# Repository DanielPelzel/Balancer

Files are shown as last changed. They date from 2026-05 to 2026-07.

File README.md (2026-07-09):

# Self Balancing Robot

A two-wheeled, self-balancing robot driven by a PID controller and a complementary filter.

## Demo Video
Self Balancing Robot PID (https://www.youtube.com/shorts/EBAI_rJyQvA)

## Hardware
* **Motor:** N20 DC Motors 6V 500RPM
* **Motor-Driver:** DRV8833
* **Microcontroller:** ESP32 DevKit
* **IMU:** MPU6050
* **Chassis:** Custom 3D-printed enclosure

## Software
* **Language:** C++ (PlatformIO)
* **GUI:** Python, PyQt5
* **Filter:** Complementary Filter
* **Controller:** PID

## Problems and Solutions

### Motor does not turn because of deadzone
* **Problem:** The motors have a deadzone that changes depending on the weight of the robot.
* **Solution:** I built a custom tool to dynamically change the PWM value via a PyQt5 GUI. This calibration tool can easily be reused in future projects.

### Motors react too late to balance the robot
* **Problem:** The motors reacted too slowly to keep the robot balanced.
* **Solution:** I went through multiple iterations. First, I realized the initial motors were incorrect, so I switched to N20 Motors with 500RPM. When the problem persisted, I tried raising the center of gravity, which also didn't work. Ultimately, I concluded that the motors were too weak for the robot's overall weight. I replaced the motor driver with a smaller, lighter one and redesigned the physical construction to be much more compact. Since the motors also had a deadzone, I used my custom GUI (linked below) to find the exact minimum PWM value needed to spin the motors.
* **Link:** [https://github.com/DanielPelzel/pwm-motor-calibrator]

### Noise in the Angle Graph
* **Problem:** There is too much noise in the angle data, caused by the limitations of the complementary filter and electromagnetic interference (EMI) between the motor driver and the MPU6050.
* **Status:** I decided to conclude this project as a successful proof of concept and move on to new mechatronic challenges. 
* **Possible Solutions:** Upgrading from a complementary filter to a Kalman filter would yield smoother data. Furthermore, physically relocating the motor driver further away from the MPU6050 would mitigate the electromagnetic interference.

### Complicated PID Tuning
* **Problem:** Tuning the PID controller was very tedious because I had to edit and flash the code after every single adjustment.
* **Solution:** I developed a PyQt5 GUI to monitor the PWM output and the robot's angle in real-time, allowing me to tweak the PID values on the fly while the robot is running.

## What I Learned
* Implementing and tuning a PID controller
* Creating electronic schematics
* Adapting mechanical designs to specific hardware constraints (motor specifications)
* Implementing a complementary filter for sensor fusion
* Building PyQt5 tools to calibrate drivers and tune PID controllers
* Identifying and handling electromagnetic interference (EMI) in hardware design

## Schematic
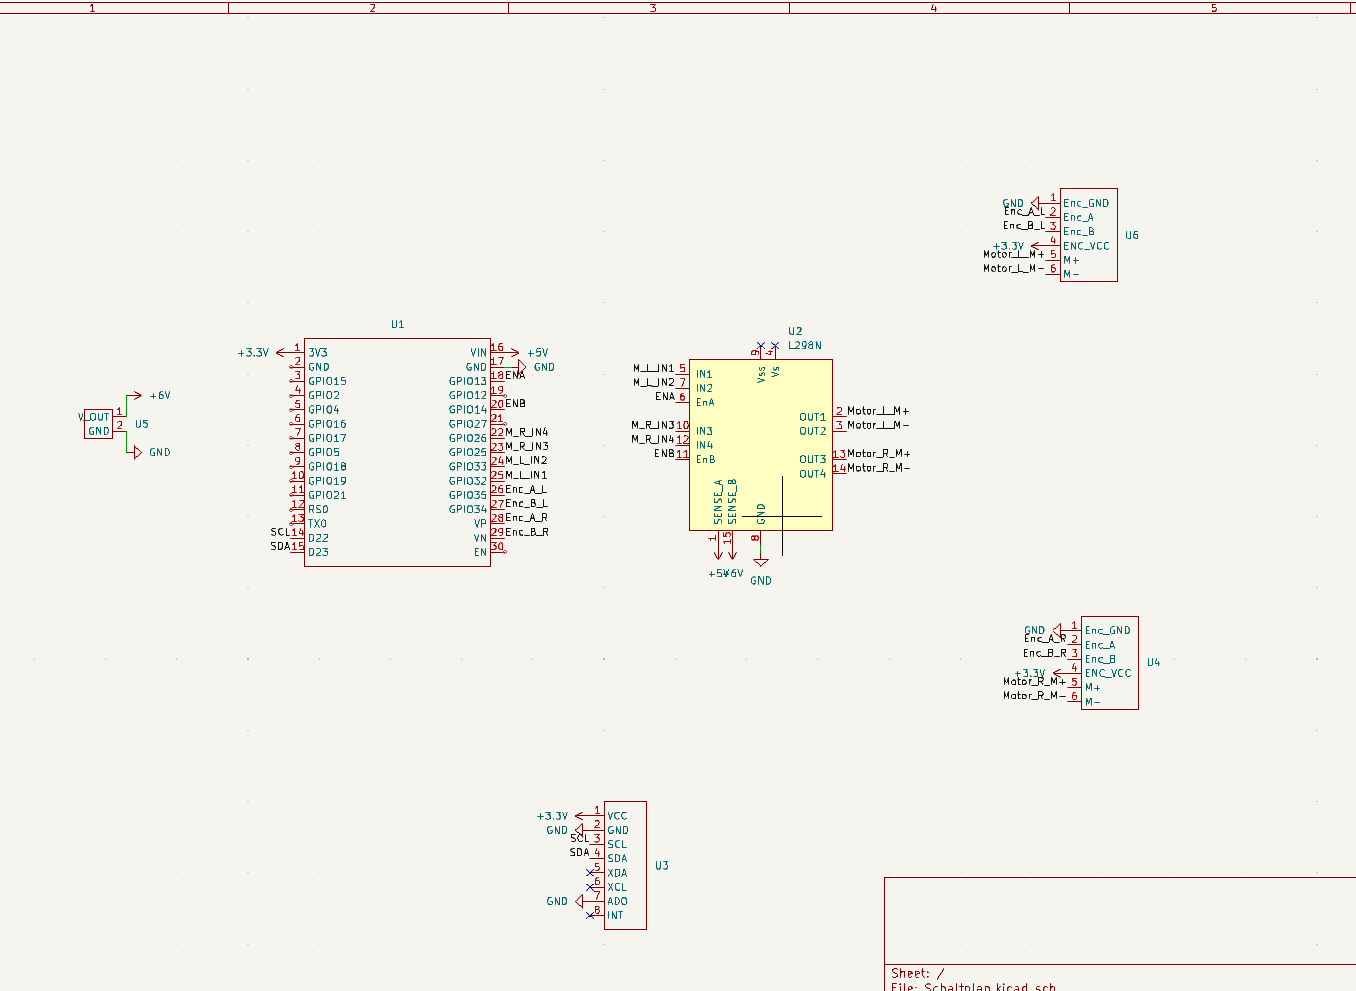
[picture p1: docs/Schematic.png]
Schematic


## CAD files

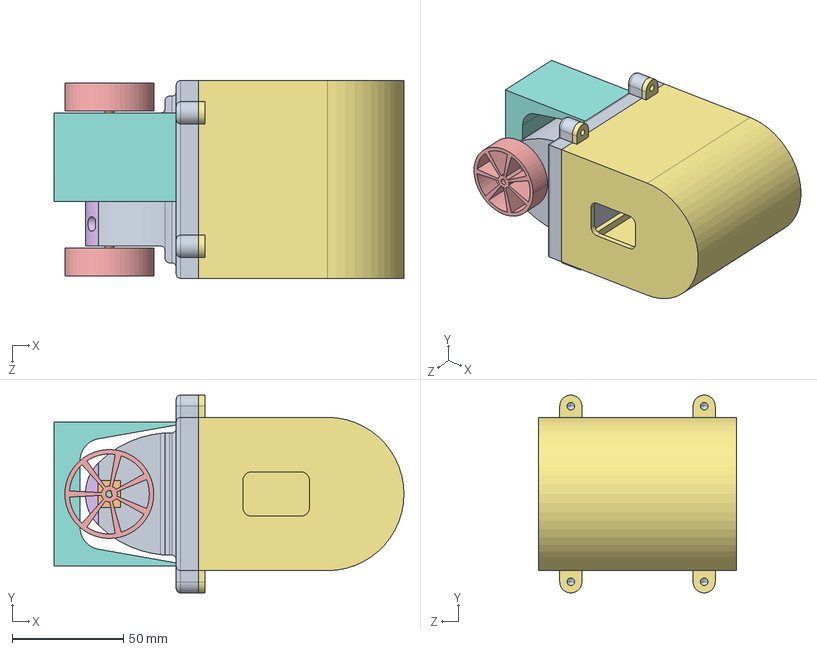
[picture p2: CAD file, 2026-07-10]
CAD/Balancer.STEP
157.5 x 89.0 x 89.0 mm
Hülle
Motorgehäuse x 2
Welle x 2
Rad x 2
Deckel
Teil1^Balancer
Teil2^Balancer

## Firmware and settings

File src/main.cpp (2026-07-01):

#include <Arduino.h>
#include "config.h"
#include "balancer.h"
#include "communiation.h"

Balancer balancer;
Communication com;

void setup() {
    Serial.begin(115200);
    balancer.init();
}

void loop() {
    float output = balancer.update();

    static unsigned long lastPrint = 0;
    if (millis() - lastPrint > 20) {
        com.sendData(balancer.getAngle(), output);
        lastPrint = millis();
    }
    com.receiveData(balancer);
    delay(5);
}

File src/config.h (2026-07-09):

#ifndef CONFIG_H
#define CONFIG_H


//Pin Belegungen
//In
#define In4 25
#define In3 26
#define In2 33
#define  In1 32

#define SLEEP_PIN 12 

//MPU 6050
#define SCL_PIN 22
#define SDA_PIN 23

#define PWM_FREQ 1000
#define PWM_RES  8
#define PWM_CH_A1 0
#define PWM_CH_A2 1
#define PWM_CH_B1 2
#define PWM_CH_B2 3

//MPU Range
#define MPU_accel_Range MPU6050_RANGE_4_G
#define MPU_gyro_Range MPU6050_RANGE_500_DEG
#define MPU_filter_bandwidth MPU6050_BAND_44_HZ

constexpr float KP = 5.0f;
constexpr float KI = 0.0f;
constexpr float KD = 0.0f;
constexpr float ANGLE_OFFSET = 0.0f;

#define drehachse az //auswhählen zwischen ax ay und az

#define TOTPUNKT 40


#endif

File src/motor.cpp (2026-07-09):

#include "motor.h"

#include <Arduino.h>
#include "config.h"

Motor::Motor(int in1, int in2, int pwmCh1, int pwmCh2) {
    _in1 = in1;
    _in2 = in2;
    _pwmCh1 = pwmCh1;
    _pwmCh2 = pwmCh2;

    ledcSetup(_pwmCh1, PWM_FREQ, PWM_RES);
    ledcSetup(_pwmCh2, PWM_FREQ, PWM_RES);
    ledcAttachPin(_in1, _pwmCh1);
    ledcAttachPin(_in2, _pwmCh2);
}

void Motor::forward(int speed) {
    ledcWrite(_pwmCh1, speed);
    ledcWrite(_pwmCh2, 0);
}

void Motor::backward(int speed) {
    ledcWrite(_pwmCh1, 0);
    ledcWrite(_pwmCh2, speed);
}

void Motor::stop() {
    ledcWrite(_pwmCh1, 0);
    ledcWrite(_pwmCh2, 0);
}

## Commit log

2026-05-01 add schematic
    [Schaltplan.kicad_pcb, Schaltplan.kicad_sch]
2026-05-01 add picture
    [Schaltplan.kicad_sch]
2026-05-01 Add README with project title and schematic image
2026-05-03 add test code for motors
2026-05-04 add PID class
    [Schaltplan.kicad_sch]
2026-05-04 add MPU Sensor class
2026-05-04 Tuned PID but still not working
    [config.h, main.cpp]
2026-06-30 neue PyQt5 Visualisierung erstellt für zukünftige PID regelung
2026-07-01 PID Spinboxed hinzugefügt
2026-07-01 motor output Widget hinzugefügt
2026-07-01 PWM_Tests und Totpunktanpassung
2026-07-09 final PID tuning
2026-07-10 add CAD files
    [Balancer.STEP]
